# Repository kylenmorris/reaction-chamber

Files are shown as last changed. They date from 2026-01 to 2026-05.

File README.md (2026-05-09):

# Reaction Chamber for Pathogen Detection in Crops

Badges, platform, license, status

## About the Project
<!-- ##################### -->

Lorem ipsum dolor sit amet, consectetur adipiscing elit, sed do eiusmod tempor incididunt ut labore et dolore magna aliqua. Ut enim ad minim veniam, quis nostrud exercitation ullamco laboris nisi ut aliquip ex ea commodo consequat. 

## System Architecture
<!-- ##################### -->

### Block Diagram
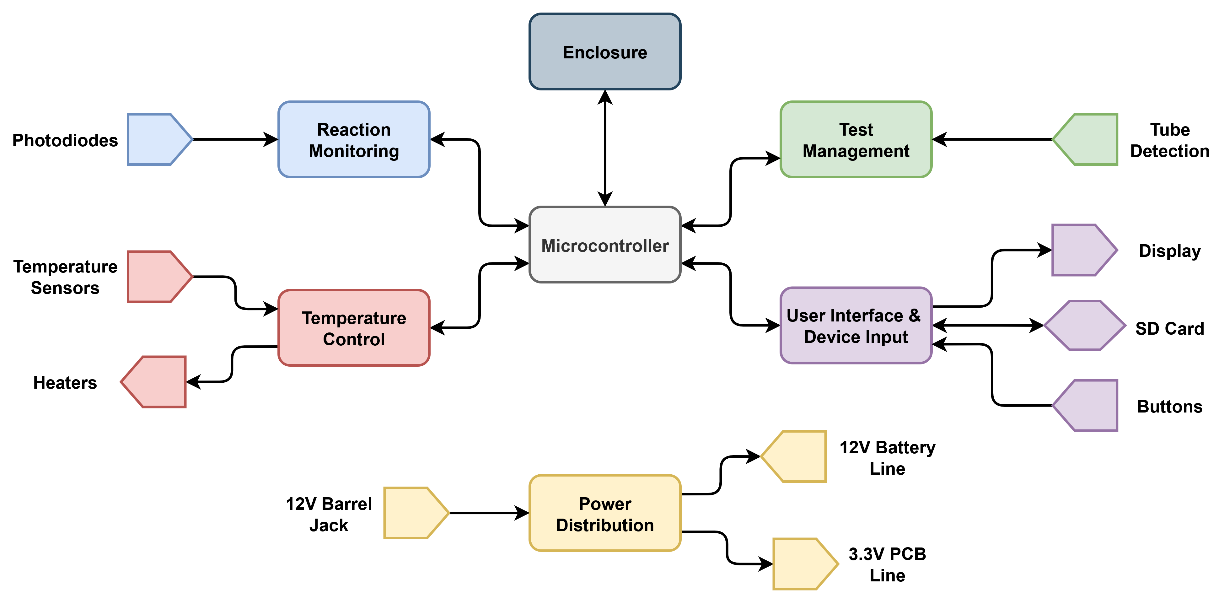
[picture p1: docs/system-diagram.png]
system block diagram


### Images

### PCBs

## Software Architecture
<!-- ##################### -->

### Software Diagram
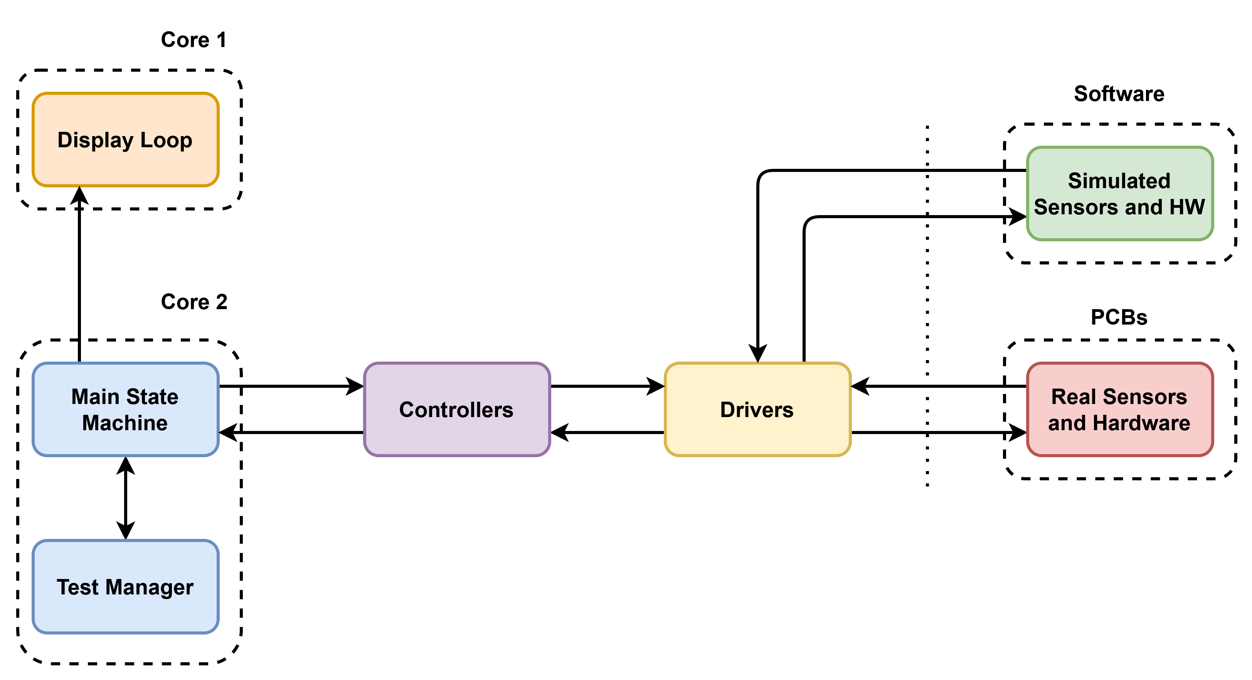
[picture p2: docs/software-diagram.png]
software block diagram


### State Diagram

### Hardware Abstraction

### Other Headers

## Hardware Overview
<!-- ##################### -->

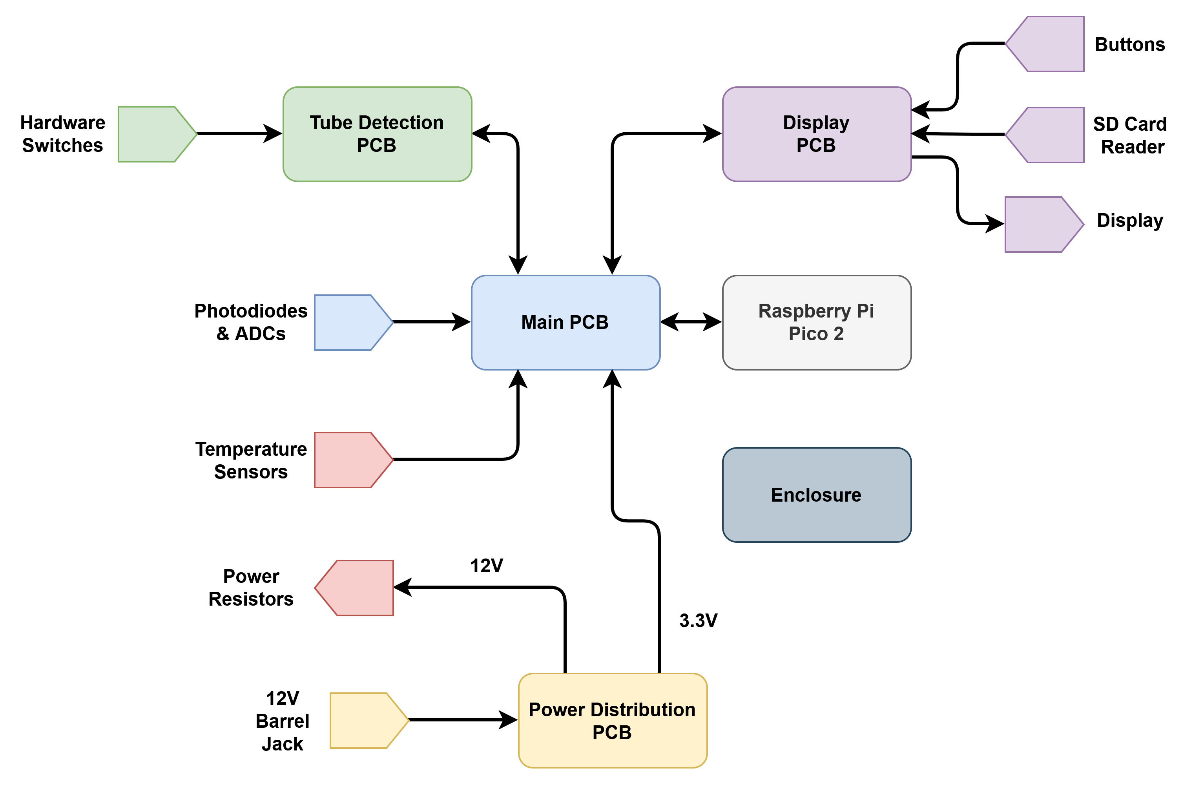
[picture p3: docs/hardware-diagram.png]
hardware block diagram


## Design Decisions
<!-- ##################### -->

## Build and Flash Instructions
<!-- ##################### -->

### Prerequisites
* Raspberry Pi Pico SDK
  ```sh
  installation here
  ```
* CMake
  ```sh
  installation here
  ```

### Compilation and Flashing
While this project does make use of the Raspberry Pi Pico extension, there can be issues using it when first cloning the project. We are using CMake and Ninja for compilation, as is default for the Pico.
After pulling, navigate into the .\code\ directory
```
cd .\code
```
Create the build folder
```
New-Item -ItemType Directory -Name build ; cd build
```
Run CMake with Ninja, and build the project
```
cmake -G Ninja ..
ninja
```

### Running Tests

### License and Acknowledgements
MIT License 

Built for an industry partner as part of a capstone project. The implementation is original work.

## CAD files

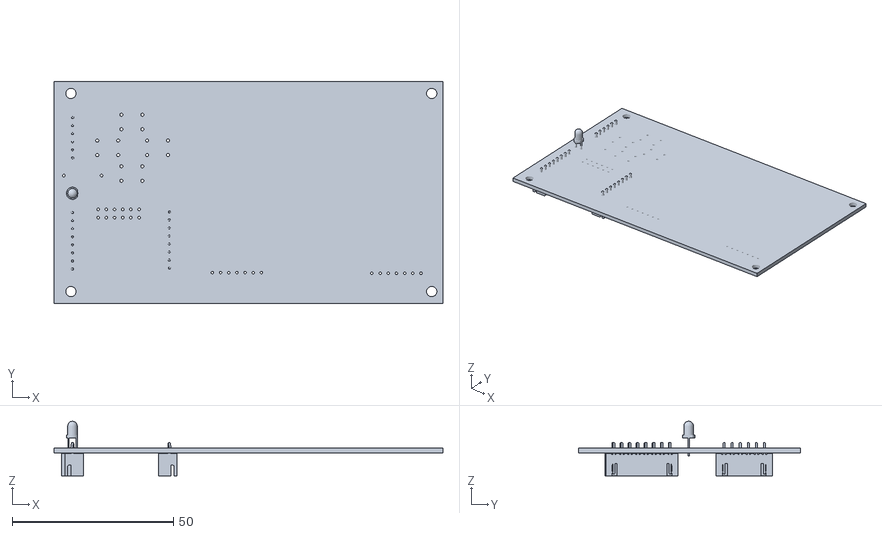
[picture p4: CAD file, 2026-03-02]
PCB/display-pcb/display-pcb.stl
120.8 x 69.0 x 17.0

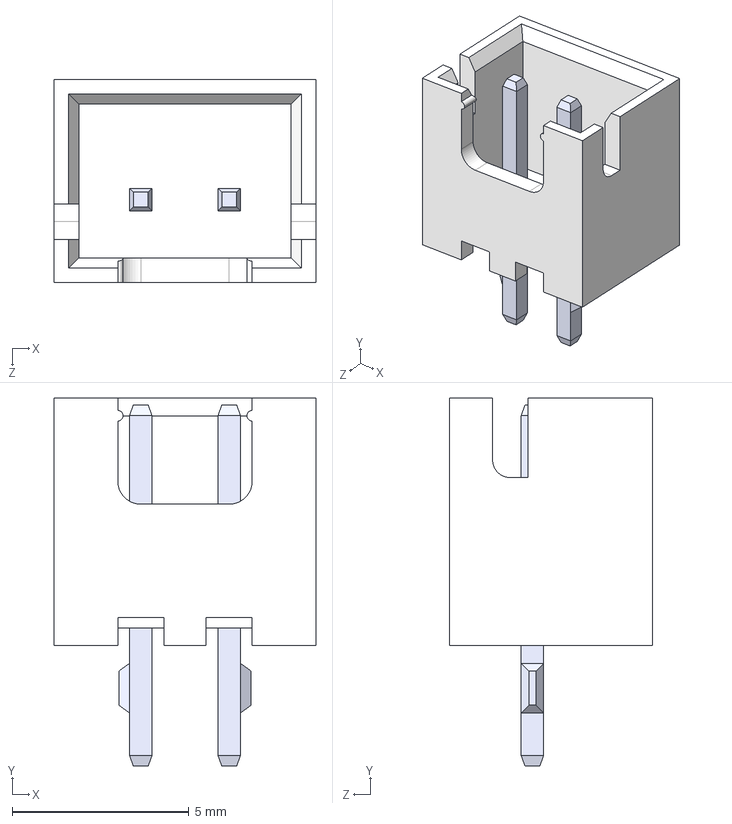
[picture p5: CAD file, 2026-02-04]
PCB/KiCad_parts/B2B_XH_A/B2B-XH-A.step
7.40 x 10.4 x 5.75 mm

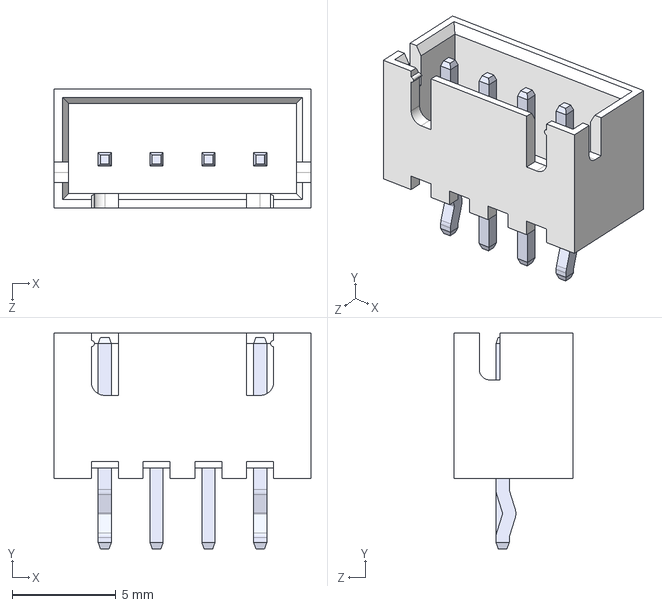
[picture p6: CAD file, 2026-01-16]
PCB/KiCad_parts/B4B_XH_A/B4B-XH-A.step
12.4 x 10.4 x 5.75 mm

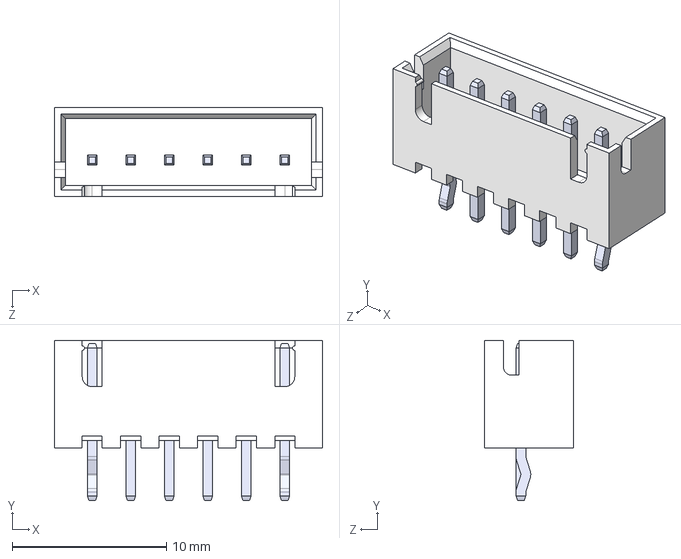
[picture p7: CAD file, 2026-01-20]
PCB/KiCad_parts/B6B-XH-A/B6B-XH-A.step
17.4 x 10.4 x 5.75 mm

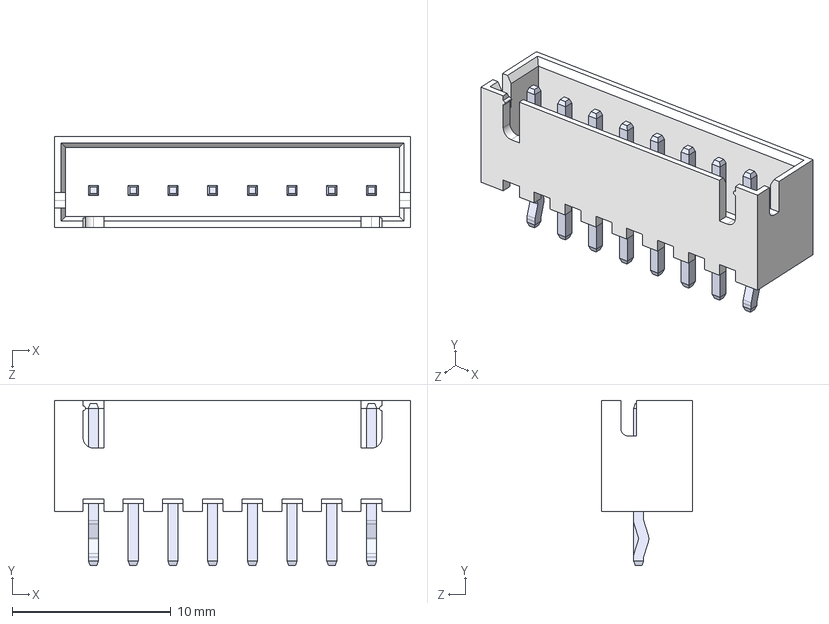
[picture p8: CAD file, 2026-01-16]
PCB/KiCad_parts/B8B_XH_A/B8B-XH-A.step
22.4 x 10.4 x 5.75 mm

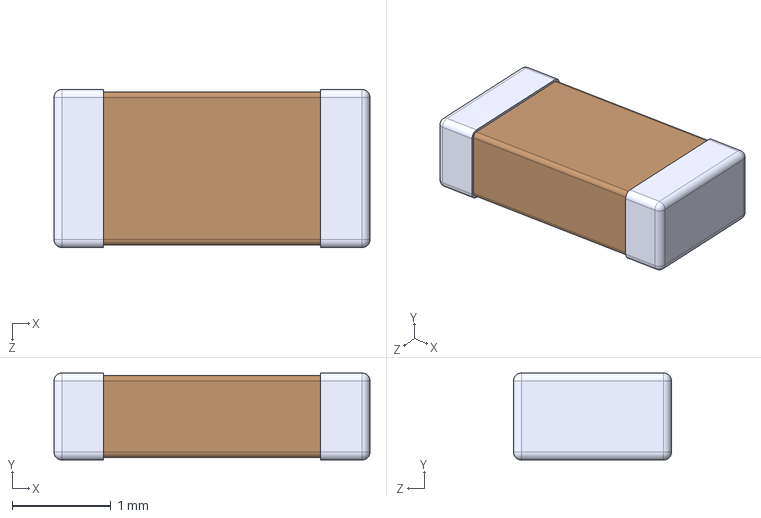
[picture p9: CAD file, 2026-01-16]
PCB/KiCad_parts/C1206C104K5RACTU/C1206C104K5RACTU.step
3.20 x 0.88 x 1.60 mm

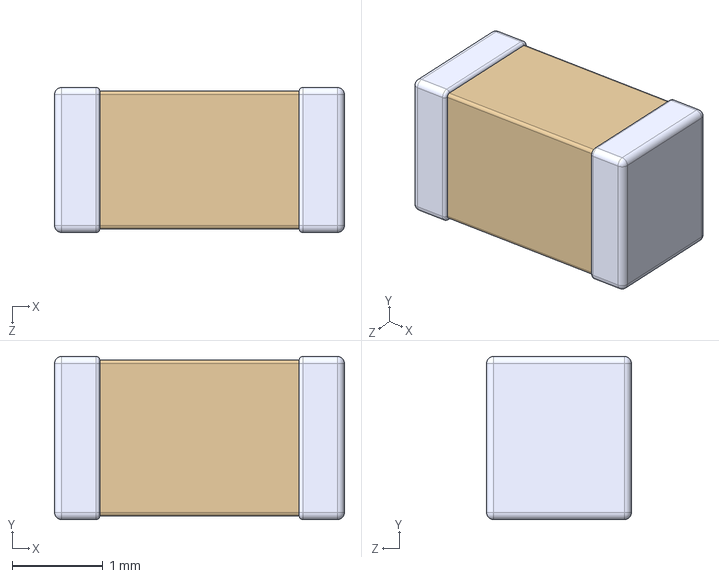
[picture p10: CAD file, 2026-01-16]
PCB/KiCad_parts/CL31A106KBHNNNE/CL31A106KBHNNNE.step
3.20 x 1.80 x 1.60 mm

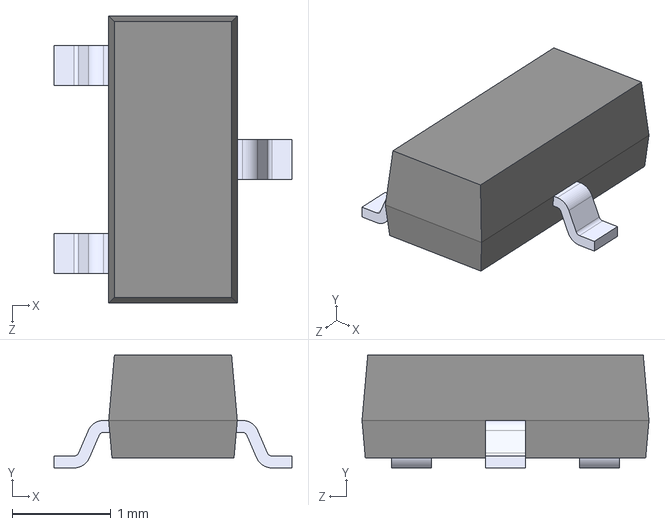
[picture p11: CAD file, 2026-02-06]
PCB/KiCad_parts/DMG2305UX_7/DMG2305UX-7.step
2.40 x 1.14 x 2.90 mm

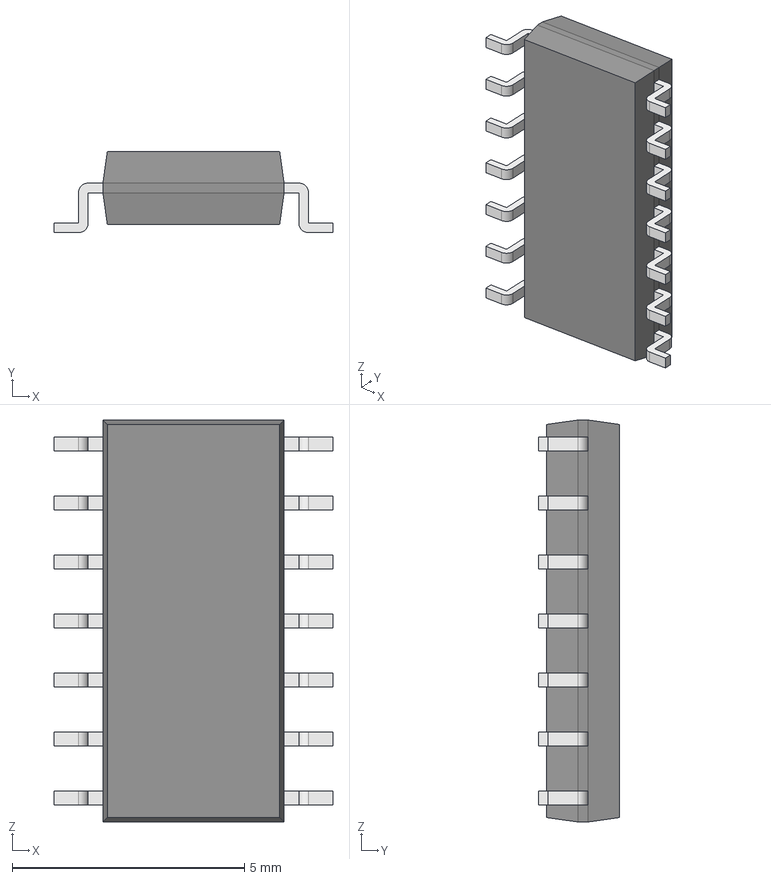
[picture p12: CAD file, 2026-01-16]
PCB/KiCad_parts/LMC660CMX_NOPB/LMC660CM.step
6.00 x 1.75 x 8.65 mm
Body001 (Mirror #1) x 7
XY-plane x 12
X-axis x 12

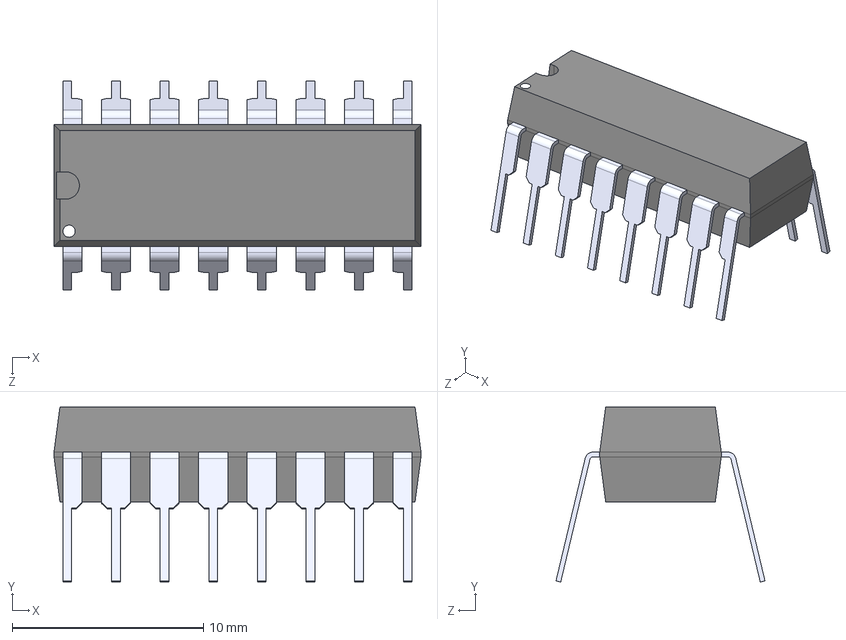
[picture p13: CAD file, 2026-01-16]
PCB/KiCad_parts/MCP3208_CI_P/MCP3208-CI_P.step
19.2 x 9.14 x 10.9 mm

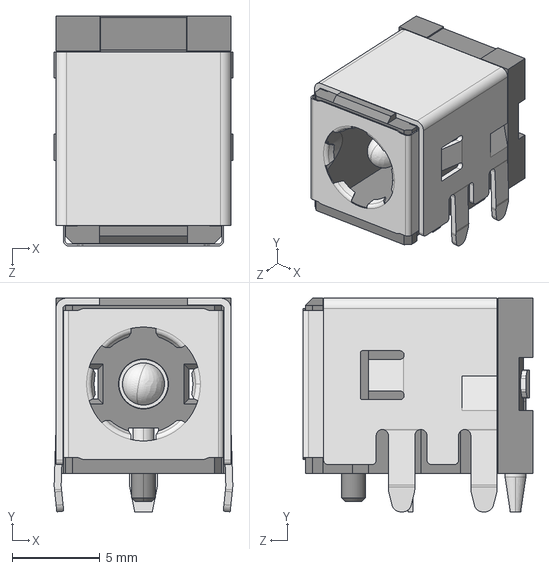
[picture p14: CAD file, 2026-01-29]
PCB/KiCad_parts/PJ_082BH/PJ-082BH.step
10.2 x 12.2 x 13.1 mm

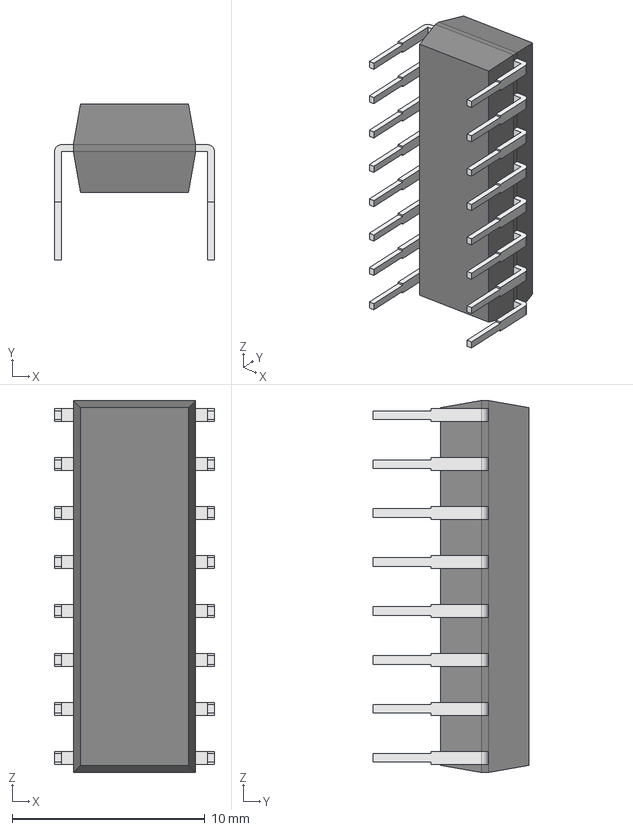
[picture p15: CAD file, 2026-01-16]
PCB/KiCad_parts/SN74HC165N/SN74HC165N.step
8.31 x 8.08 x 19.3 mm
Body001 (Mirror #1) x 9

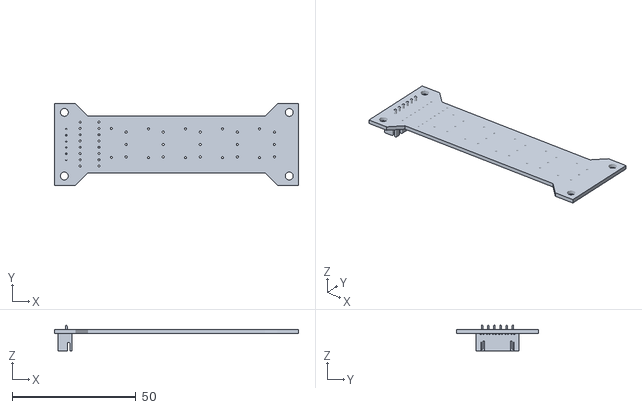
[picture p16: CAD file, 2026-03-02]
PCB/tube_detection_pcb/tube_detection_pcb/tube_detection_pcb.stl
98.8 x 33.0 x 10.4

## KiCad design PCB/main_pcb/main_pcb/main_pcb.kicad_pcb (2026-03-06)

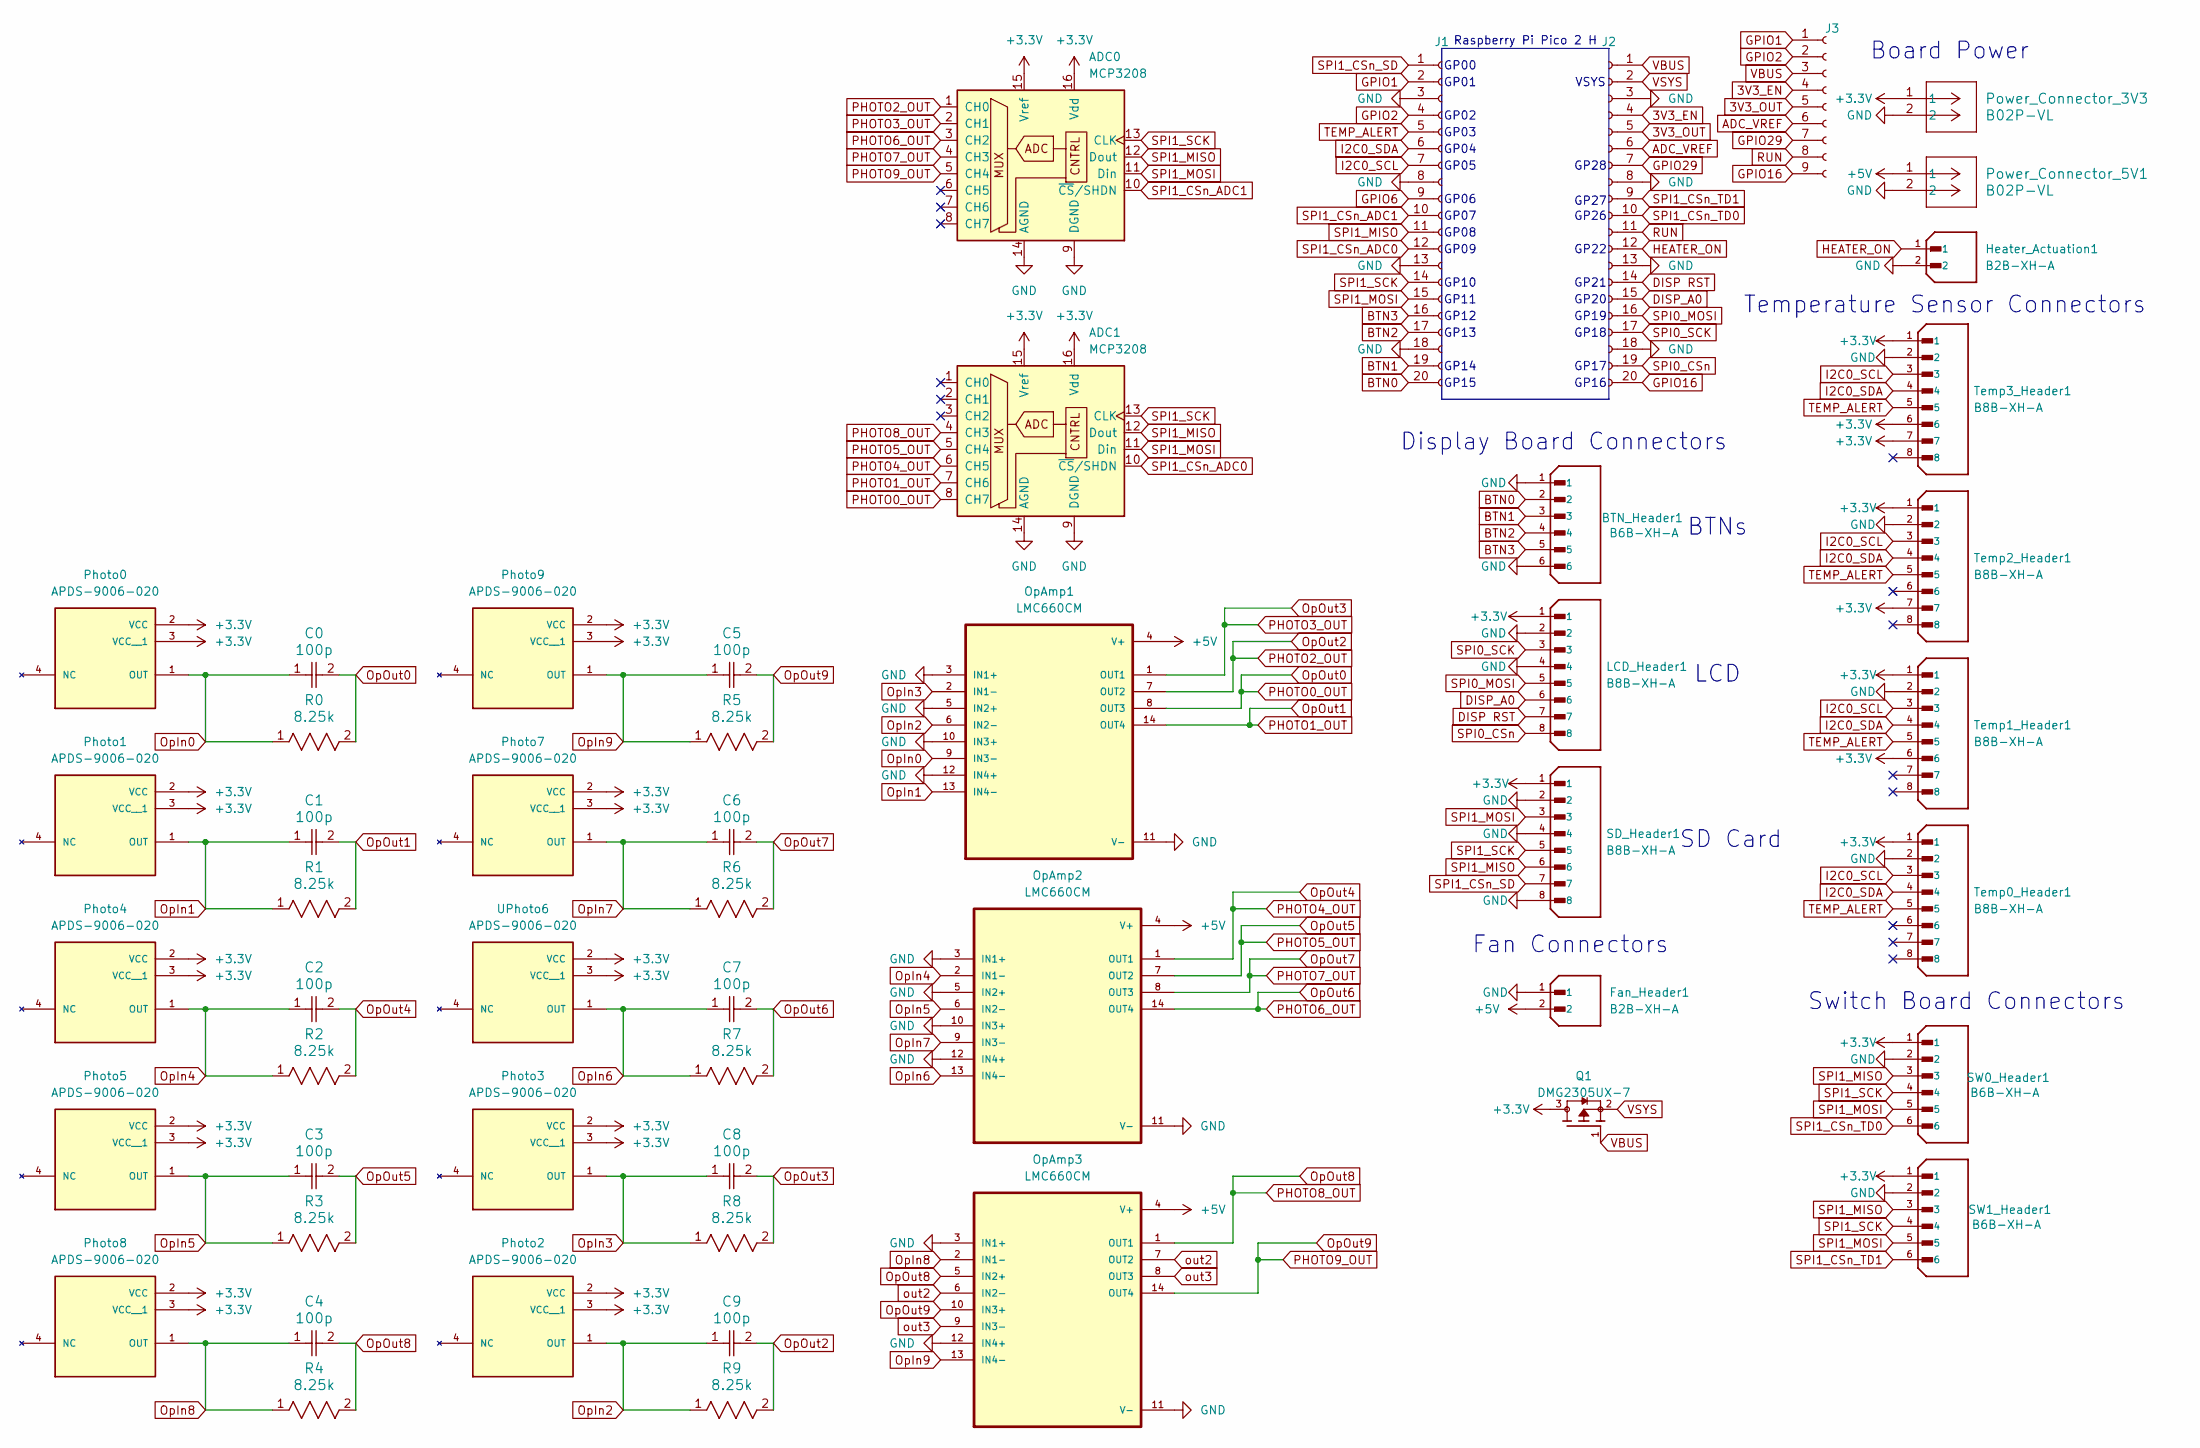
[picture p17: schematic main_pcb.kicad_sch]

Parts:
ADC0, ADC1: MCP3208; DIP254P762X432-16
BTN_Header1: B6B-XH-A; JST_XH_B6B-XH-A_1x06_P2.50mm_Vertical; PARTREV 7/4/21; DigiKey_Part_Number 455-B6B-XH-A-ND
C0, C1, C2, C3, C4, C5, C6, C7, C8, C9: 100p; C_1206_3216Metric_Pad1.33x1.80mm_HandSolder
Fan_Header1: B2B-XH-A; JST_B2B-XH-A; PARTREV N/A
Heater_Actuation1: B2B-XH-A; JST_B2B-XH-A; PARTREV N/A
J1, J2: Conn_01x20_Socket; PinSocket_1x20_P2.54mm_Vertical
J3: Conn_01x09_Socket; PinSocket_1x09_P2.54mm_Vertical
LCD_Header1: B8B-XH-A; JST_XH_B8B-XH-A_1x08_P2.50mm_Vertical; PARTREV 7/4/21
OpAmp1, OpAmp2, OpAmp3: LMC660CM; SOIC127P600X175-14N
Photo0, Photo1, Photo2, Photo3, Photo4, Photo5, Photo7, Photo8, Photo9: APDS-9006-020; photodiode_v4; PARTREV January 16, 2007
Power_Connector_3V3, Power_Connector_5V1: B02P-VL; CONN_B02P-VL_JST
Q1: DMG2305UX-7; SOT91P240X110-3N_DMG2305UX-7; PARTREV 09/2018
R0, R1, R2, R3, R4, R5, R6, R7, R8, R9: 8.25k; YAG_MF25_YAG
SD_Header1: B8B-XH-A; JST_XH_B8B-XH-A_1x08_P2.50mm_Vertical; PARTREV 7/4/21
SW0_Header1, SW1_Header1: B6B-XH-A; JST_XH_B6B-XH-A_1x06_P2.50mm_Vertical; PARTREV 7/4/21; DigiKey_Part_Number 455-B6B-XH-A-ND
Temp0_Header1, Temp1_Header1, Temp2_Header1, Temp3_Header1: B8B-XH-A; JST_XH_B8B-XH-A_1x08_P2.50mm_Vertical; PARTREV 7/4/21
UPhoto6: APDS-9006-020; photodiode_v4; PARTREV January 16, 2007

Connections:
3V3_EN: J2.4, J3.4
3V3_OUT: J2.5, J3.5
+3.3V: ADC0.15 (Vref), ADC0.16 (Vdd), ADC1.15 (Vref), ADC1.16 (Vdd), LCD_Header1.1, Photo0.2 (VCC), Photo0.3 (VCC__1), Photo1.2 (VCC), Photo1.3 (VCC__1), Photo2.2 (VCC), Photo2.3 (VCC__1), Photo3.2 (VCC), Photo3.3 (VCC__1), Photo4.2 (VCC), Photo4.3 (VCC__1), Photo5.2 (VCC), Photo5.3 (VCC__1), Photo7.2 (VCC), Photo7.3 (VCC__1), Photo8.2 (VCC), Photo8.3 (VCC__1), Photo9.2 (VCC), Photo9.3 (VCC__1), Power_Connector_3V3.1, Q1.3, SD_Header1.1, SW0_Header1.1, SW1_Header1.1, Temp0_Header1.1, Temp1_Header1.1, Temp1_Header1.6, Temp2_Header1.1, Temp2_Header1.7, Temp3_Header1.1, Temp3_Header1.6, Temp3_Header1.7, UPhoto6.2 (VCC), UPhoto6.3 (VCC__1)
+5V: Fan_Header1.2, OpAmp1.4 (V+), OpAmp2.4 (V+), OpAmp3.4 (V+), Power_Connector_5V1.1
ADC_VREF: J2.6, J3.6
BTN0: BTN_Header1.2, J1.20
BTN1: BTN_Header1.3, J1.19
BTN2: BTN_Header1.4, J1.17
BTN3: BTN_Header1.5, J1.16
DISP RST: J2.14, LCD_Header1.7
DISP_A0: J2.15, LCD_Header1.6
GND: ADC0.9 (DGND), ADC0.14 (AGND), ADC1.9 (DGND), ADC1.14 (AGND), BTN_Header1.1, BTN_Header1.6, Fan_Header1.1, Heater_Actuation1.2, J1.3, J1.8, J1.13, J1.18, J2.3, J2.8, J2.13, J2.18, LCD_Header1.2, LCD_Header1.4, OpAmp1.3 (IN1+), OpAmp1.5 (IN2+), OpAmp1.10 (IN3+), OpAmp1.11 (V-), OpAmp1.12 (IN4+), OpAmp2.3 (IN1+), OpAmp2.5 (IN2+), OpAmp2.10 (IN3+), OpAmp2.11 (V-), OpAmp2.12 (IN4+), OpAmp3.3 (IN1+), OpAmp3.11 (V-), OpAmp3.12 (IN4+), Power_Connector_3V3.2, Power_Connector_5V1.2, SD_Header1.2, SD_Header1.4, SD_Header1.8, SW0_Header1.2, SW1_Header1.2, Temp0_Header1.2, Temp1_Header1.2, Temp2_Header1.2, Temp3_Header1.2
GPIO1: J1.2, J3.1
GPIO2: J1.4, J3.2
GPIO6: J1.9
GPIO16: J2.20, J3.9
GPIO29: J2.7, J3.7
HEATER_ON: Heater_Actuation1.1, J2.12
I2C0_SCL: J1.7, Temp0_Header1.3, Temp1_Header1.3, Temp2_Header1.3, Temp3_Header1.3
I2C0_SDA: J1.6, Temp0_Header1.4, Temp1_Header1.4, Temp2_Header1.4, Temp3_Header1.4
OpIn0: C0.1, OpAmp1.9 (IN3-), Photo0.1 (OUT), R0.1
OpIn1: C1.1, OpAmp1.13 (IN4-), Photo1.1 (OUT), R1.1
OpIn2: C9.1, OpAmp1.6 (IN2-), Photo2.1 (OUT), R9.1
OpIn3: C8.1, OpAmp1.2 (IN1-), Photo3.1 (OUT), R8.1
OpIn4: C2.1, OpAmp2.2 (IN1-), Photo4.1 (OUT), R2.1
OpIn5: C3.1, OpAmp2.6 (IN2-), Photo5.1 (OUT), R3.1
OpIn6: C7.1, OpAmp2.13 (IN4-), R7.1, UPhoto6.1 (OUT)
OpIn7: C6.1, OpAmp2.9 (IN3-), Photo7.1 (OUT), R6.1
OpIn8: C4.1, OpAmp3.2 (IN1-), Photo8.1 (OUT), R4.1
OpIn9: C5.1, OpAmp3.13 (IN4-), Photo9.1 (OUT), R5.1
OpOut0: ADC1.8 (CH7), C0.2, OpAmp1.8 (OUT3), R0.2
OpOut1: ADC1.7 (CH6), C1.2, OpAmp1.14 (OUT4), R1.2
OpOut2: ADC0.1 (CH0), C9.2, OpAmp1.7 (OUT2), R9.2
OpOut3: ADC0.2 (CH1), C8.2, OpAmp1.1 (OUT1), R8.2
OpOut4: ADC1.6 (CH5), C2.2, OpAmp2.1 (OUT1), R2.2
OpOut5: ADC1.5 (CH4), C3.2, OpAmp2.7 (OUT2), R3.2
OpOut6: ADC0.3 (CH2), C7.2, OpAmp2.14 (OUT4), R7.2
OpOut7: ADC0.4 (CH3), C6.2, OpAmp2.8 (OUT3), R6.2
OpOut8: ADC1.4 (CH3), C4.2, OpAmp3.1 (OUT1), OpAmp3.5 (IN2+), R4.2
OpOut9: ADC0.5 (CH4), C5.2, OpAmp3.10 (IN3+), OpAmp3.14 (OUT4), R5.2
RUN: J2.11, J3.8
SPI0_CSn: J2.19, LCD_Header1.8
SPI0_MOSI: J2.16, LCD_Header1.5
SPI0_SCK: J2.17, LCD_Header1.3
SPI1_CSn_ADC0: ADC1.10 (~CS/SHDN), J1.12
SPI1_CSn_ADC1: ADC0.10 (~CS/SHDN), J1.10
SPI1_CSn_SD: J1.1, SD_Header1.7
SPI1_CSn_TD0: J2.10, SW0_Header1.6
SPI1_CSn_TD1: J2.9, SW1_Header1.6
SPI1_MISO: ADC0.12 (Dout), ADC1.12 (Dout), J1.11, SD_Header1.6, SW0_Header1.3, SW1_Header1.3
SPI1_MOSI: ADC0.11 (Din), ADC1.11 (Din), J1.15, SD_Header1.3, SW0_Header1.5, SW1_Header1.5
SPI1_SCK: ADC0.13 (CLK), ADC1.13 (CLK), J1.14, SD_Header1.5, SW0_Header1.4, SW1_Header1.4
TEMP_ALERT: J1.5, Temp0_Header1.5, Temp1_Header1.5, Temp2_Header1.5, Temp3_Header1.5
VBUS: J2.1, J3.3, Q1.1
VSYS: J2.2, Q1.2
out2: OpAmp3.6 (IN2-), OpAmp3.7 (OUT2)
out3: OpAmp3.8 (OUT3), OpAmp3.9 (IN3-)

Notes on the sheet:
GP18
GP06
GP11
Switch Board Connectors
GP12
GP27
SD Card
GP22
Fan Connectors
GP10
GP15
GP03
GP09
GP21
VSYS
GP05
GP16
Display Board Connectors
GP04
GP02
GP13
Temperature Sensor Connectors
GP14
GP17
GP00
Board Power
GP19
GP28
LCD
GP20
GP07
GP08
BTNs
GP26
Raspberry Pi Pico 2 H
GP01

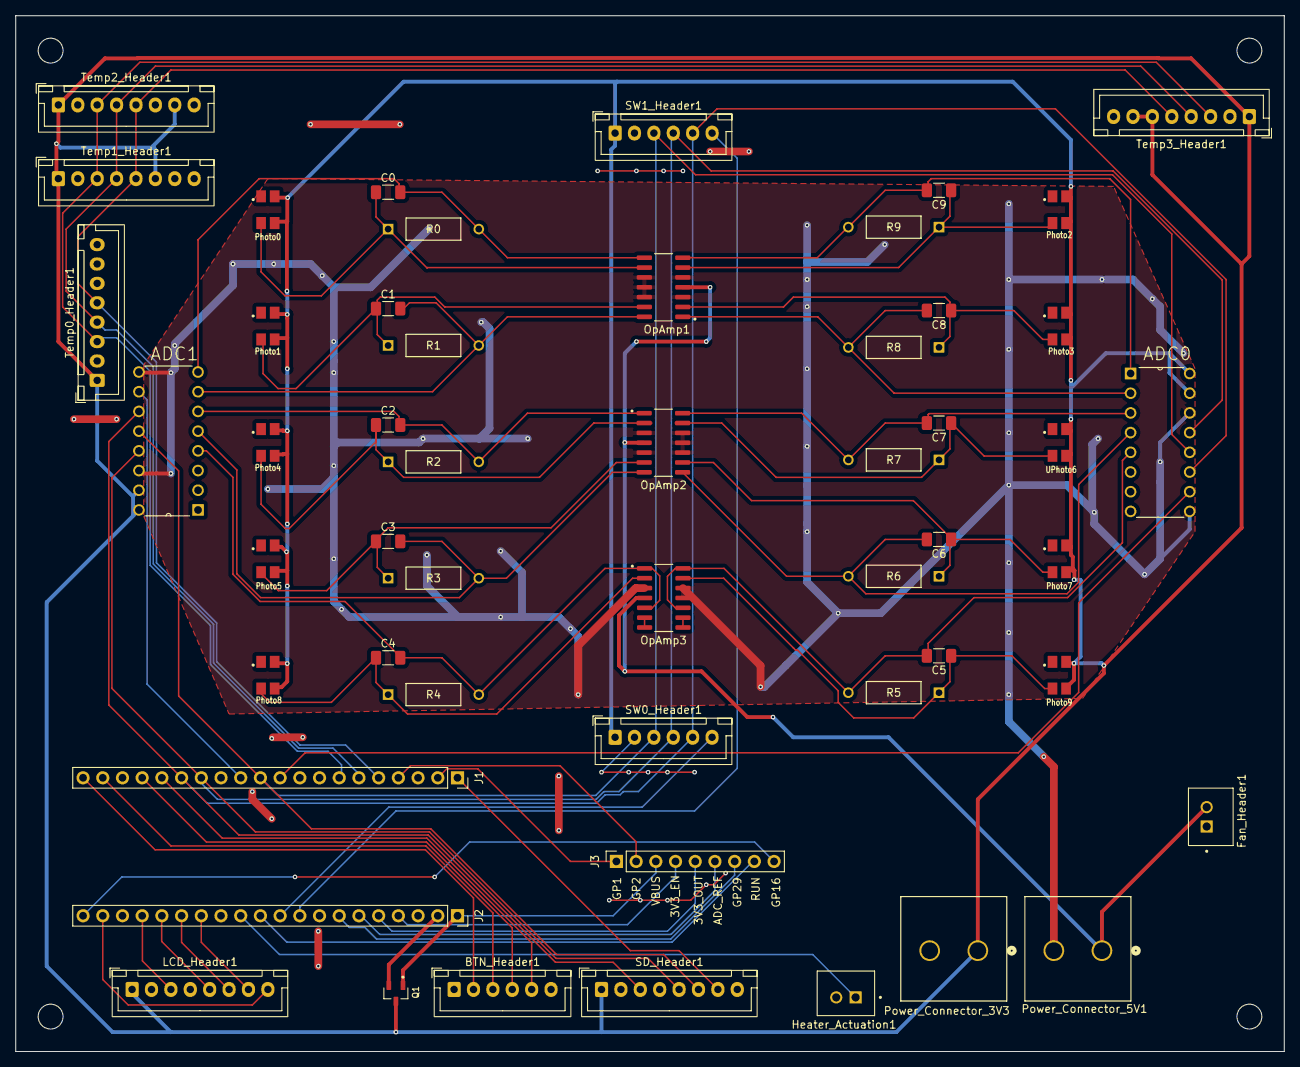
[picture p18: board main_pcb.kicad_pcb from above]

Board: 2 copper layers, 163.5 x 133.5 mm, 52 parts (0 on the bottom side), 56 nets.

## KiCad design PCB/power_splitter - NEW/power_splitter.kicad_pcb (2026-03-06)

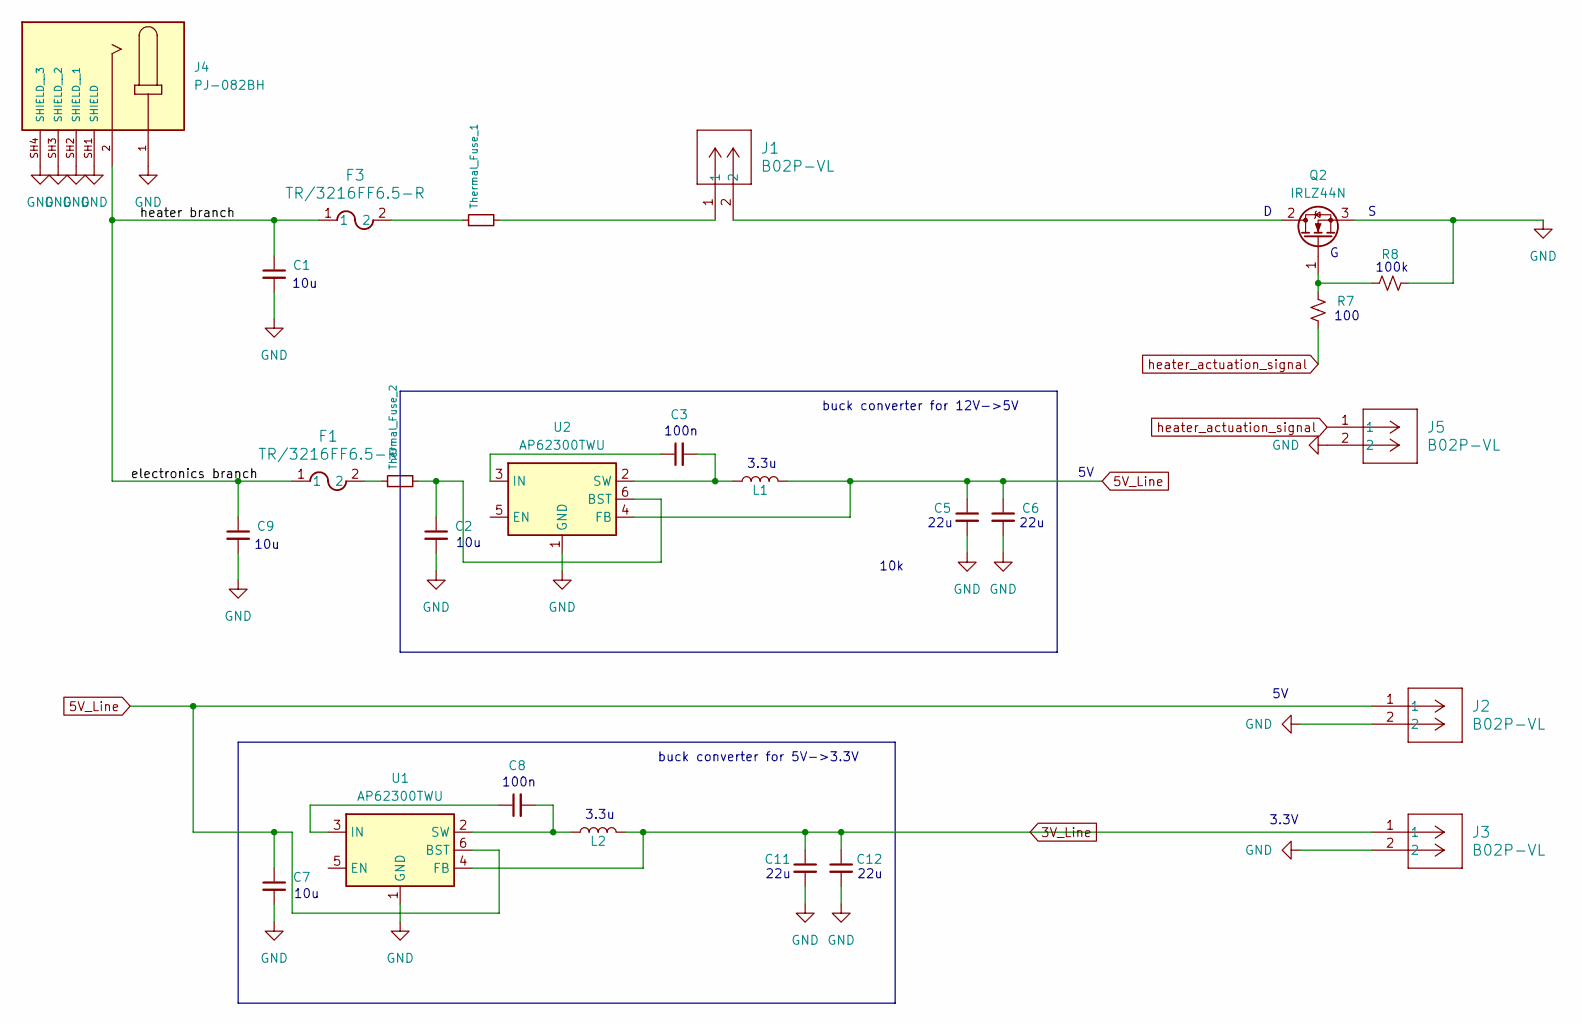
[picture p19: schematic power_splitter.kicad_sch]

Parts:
C1, C2, C3, C5, C6, C7, C8, C9, C11, C12: C_Small; C_1206_3216Metric_Pad1.33x1.80mm_HandSolder
F1, F3: TR/3216FF6.5-R; FUS_CB_3216FF
J1, J2, J3: B02P-VL; CONN_B02P-VL_JST
J4: PJ-082BH; SAMESKY_PJ-082BH; PARTREV 1.06
J5: B02P-VL; JST_NV_B02P-NV_1x02_P5.00mm_Vertical
L1, L2: L; L_Axial_L7.0mm_D3.3mm_P5.08mm_Vertical_Fastron_MICC
Q2: IRLZ44N; TO-220-3_Vertical
R7, R8: R_Small_US; YAG_MF25_YAG
Thermal_Fuse_1, Thermal_Fuse_2: R_Small; YAG_MF25_YAG
U1, U2: AP62300TWU; TSOT-23-6

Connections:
3V_Line: C11.1, C12.1, J3.1, L2.2, U1.4 (FB)
5V_Line: C5.1, C6.1, C7.1, J2.1, L1.2, U1.6 (BST), U2.4 (FB)
/electronics branch: C1.1, C9.1, F1.1, F3.1, J4.2
GND: C1.2, C2.2, C5.2, C6.2, C7.2, C9.2, C11.2, C12.2, J2.2, J3.2, J4.1, J4.SH1 (SHIELD), J4.SH2 (SHIELD__1), J4.SH3 (SHIELD__2), J4.SH4 (SHIELD__3), J5.2, Q2.3 (S), R8.2, U1.1 (GND), U2.1 (GND)
unnamed: F1.2, Thermal_Fuse_2.1
unnamed: F3.2, Thermal_Fuse_1.1
unnamed: J1.1, Thermal_Fuse_1.2
unnamed: J1.2, Q2.2 (D)
unnamed: Q2.1 (G), R7.1, R8.1
unnamed: C8.1, U1.3 (IN)
unnamed: C8.2, L2.1, U1.2 (SW)
unnamed: C2.1, Thermal_Fuse_2.2, U2.6 (BST)
unnamed: C3.1, U2.3 (IN)
unnamed: C3.2, L1.1, U2.2 (SW)
heater_actuation_signal: J5.1, R7.2

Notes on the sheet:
10u
100n
100
100k
10k
22u
3.3u
3.3V
buck converter for 12V->5V
buck converter for 5V->3.3V

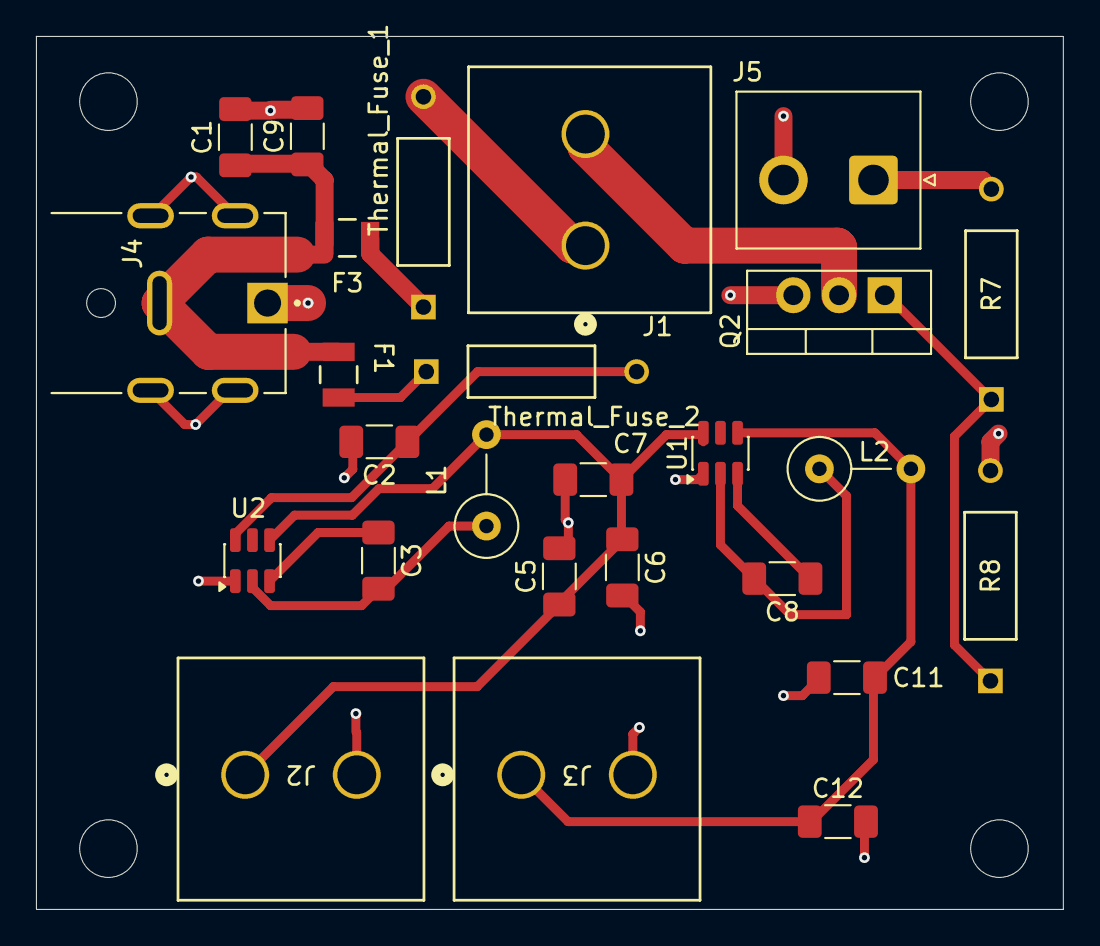
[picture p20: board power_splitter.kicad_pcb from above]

Board: 2 copper layers, 57.1 x 48.5 mm, 26 parts (0 on the bottom side), 15 nets.

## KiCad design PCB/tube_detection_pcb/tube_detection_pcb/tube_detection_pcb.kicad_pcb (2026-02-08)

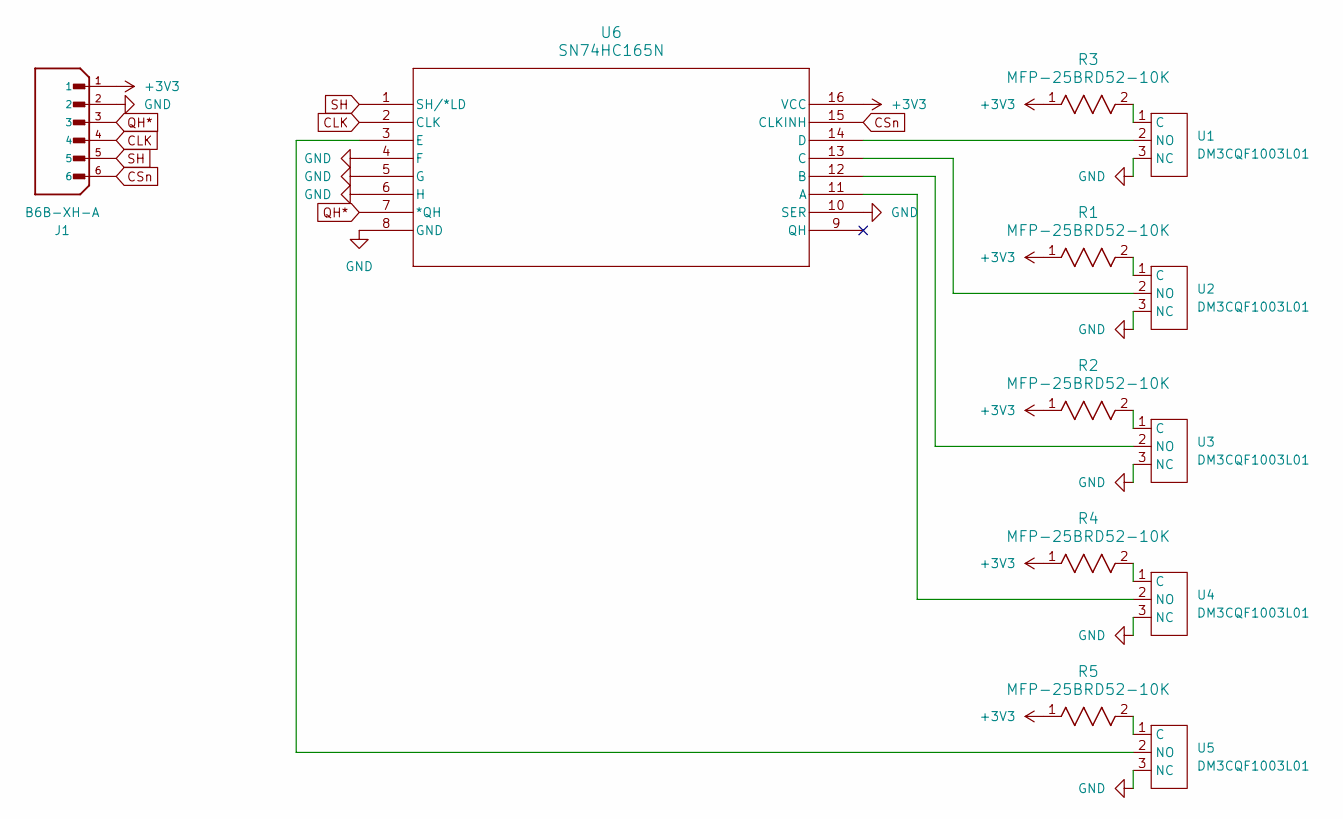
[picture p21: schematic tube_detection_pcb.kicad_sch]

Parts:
J1: B6B-XH-A; JST_XH_B6B-XH-A_1x06_P2.50mm_Vertical; PARTREV 7/4/21; DigiKey_Part_Number 455-B6B-XH-A-ND
R1, R2, R3, R4, R5: MFP-25BRD52-10K; YAG_MF25_YAG
U1, U2, U3, U4, U5: DM3CQF1003L01
U6: SN74HC165N; N16

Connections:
+3V3: J1.1, R1.1, R2.1, R3.1, R4.1, R5.1, U6.16 (VCC)
CLK: J1.4, U6.2 (CLK)
CSn: J1.6, U6.15 (CLKINH)
GND: J1.2, U1.3 (NC), U2.3 (NC), U3.3 (NC), U4.3 (NC), U5.3 (NC), U6.4 (F), U6.5 (G), U6.6 (H), U6.8 (GND), U6.10 (SER)
unnamed: R3.2, U1.1 (C)
unnamed: U1.2 (NO), U6.14 (D)
unnamed: R1.2, U2.1 (C)
unnamed: U2.2 (NO), U6.13 (C)
unnamed: R2.2, U3.1 (C)
unnamed: U3.2 (NO), U6.12 (B)
unnamed: R4.2, U4.1 (C)
unnamed: U4.2 (NO), U6.11 (A)
unnamed: R5.2, U5.1 (C)
unnamed: U5.2 (NO), U6.3 (E)
QH*: J1.3, U6.7 (*QH)
SH: J1.5, U6.1 (SH/*LD)

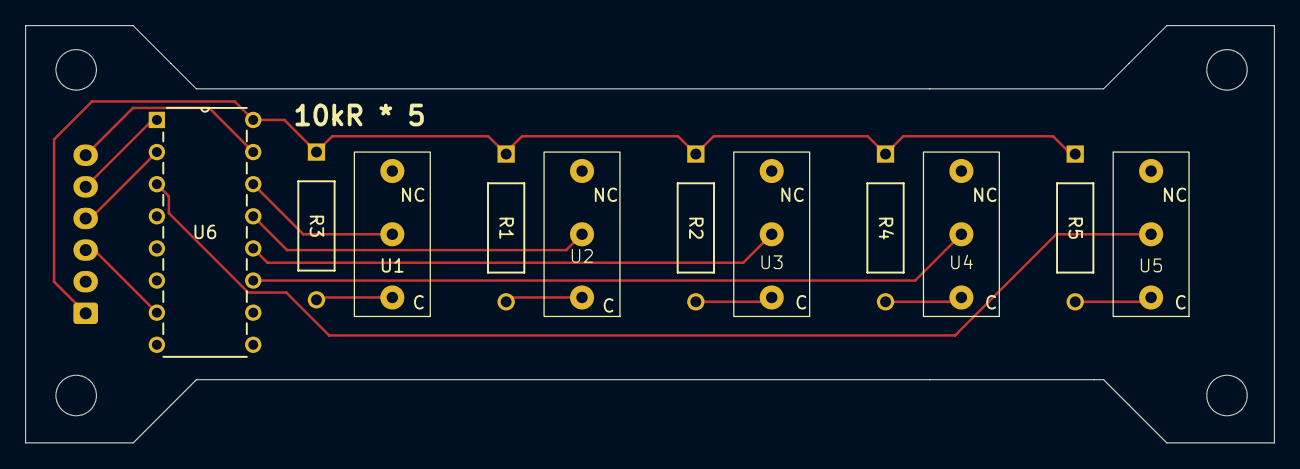
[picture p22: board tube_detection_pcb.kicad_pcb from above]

Board: 2 copper layers, 98.8 x 33.0 mm, 12 parts (1 on the bottom side), 16 nets.

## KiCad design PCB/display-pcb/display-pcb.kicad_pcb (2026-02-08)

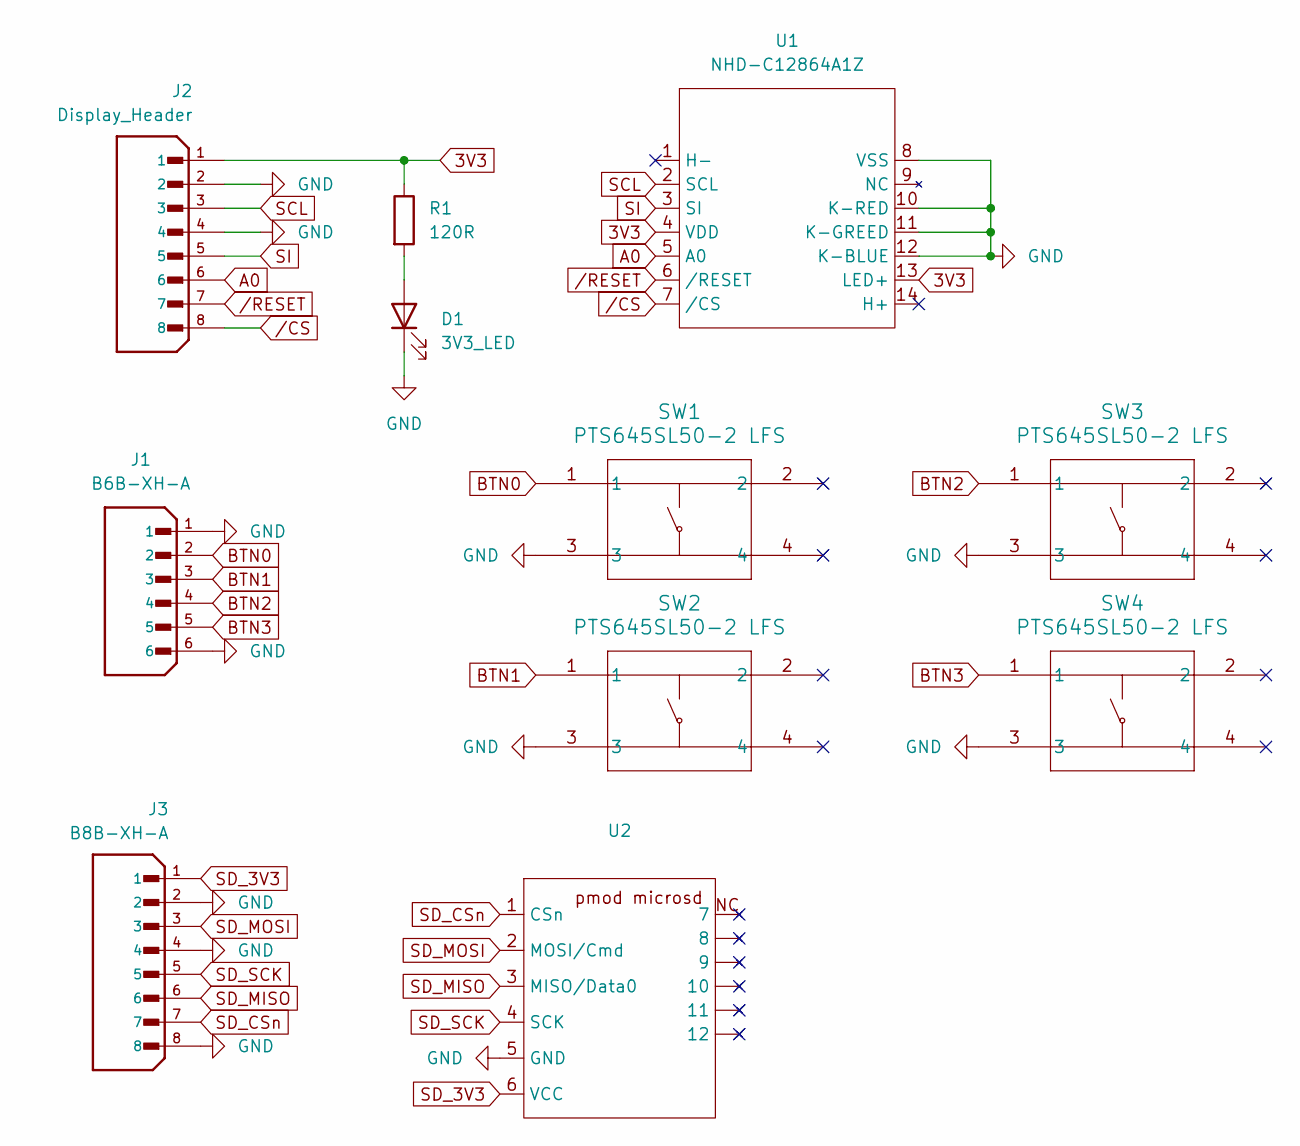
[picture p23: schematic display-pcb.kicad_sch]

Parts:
D1: 3V3_LED; LED_D3.0mm
J1: B6B-XH-A; JST_XH_B6B-XH-A_1x06_P2.50mm_Vertical; PARTREV 7/4/21; DigiKey_Part_Number 455-B6B-XH-A-ND
J2: Display_Header; JST_XH_B8B-XH-A_1x08_P2.50mm_Vertical; PARTREV 7/4/21
J3: B8B-XH-A; JST_XH_B8B-XH-A_1x08_P2.50mm_Vertical; PARTREV 7/4/21
R1: 120R; YAG_MF25_YAG
SW1, SW2, SW3, SW4: PTS645SL50-2 LFS; PTS654S_CNK
U1: NHD-C12864A1Z
U2: pmod-microsd

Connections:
3V3: J2.1, R1.1, U1.4 (VDD), U1.13 (LED+)
A0: J2.6, U1.5 (A0)
BTN0: J1.2, SW1.1
BTN1: J1.3, SW2.1
BTN2: J1.4, SW3.1
BTN3: J1.5, SW4.1
GND: D1.1 (K), J1.1, J1.6, J2.2, J2.4, J3.2, J3.4, J3.8, SW1.3, SW2.3, SW3.3, SW4.3, U1.8 (VSS), U1.10 (K-RED), U1.11 (K-GREED), U1.12 (K-BLUE), U2.5 (GND)
unnamed: D1.2 (A), R1.2
SCL: J2.3, U1.2 (SCL)
SD_3V3: J3.1, U2.6 (VCC)
SD_CSn: J3.7, U2.1 (CSn)
SD_MISO: J3.6, U2.3 (MISO/Data0)
SD_MOSI: J3.3, U2.2 (MOSI/Cmd)
SD_SCK: J3.5, U2.4 (SCK)
SI: J2.5, U1.3 (SI)
/CS: J2.8, U1.7 (/CS)
/RESET: J2.7, U1.6 (/RESET)

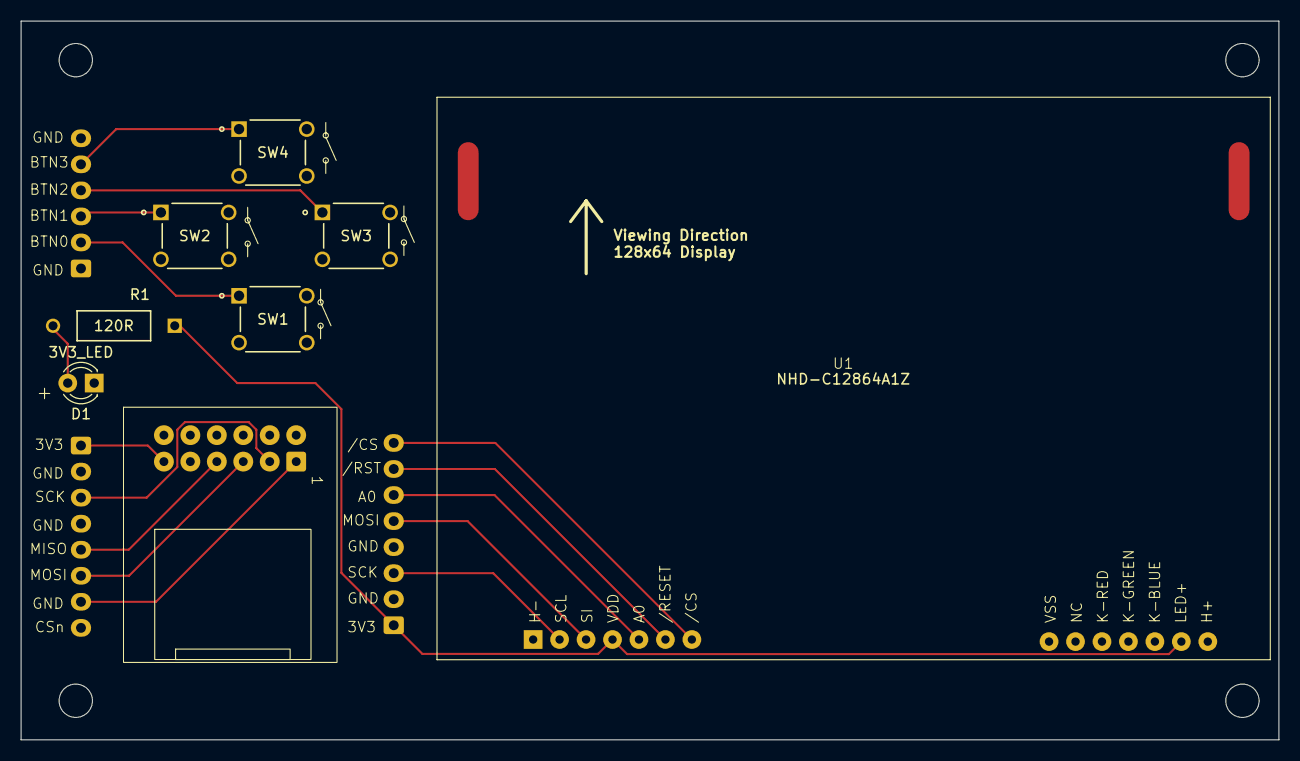
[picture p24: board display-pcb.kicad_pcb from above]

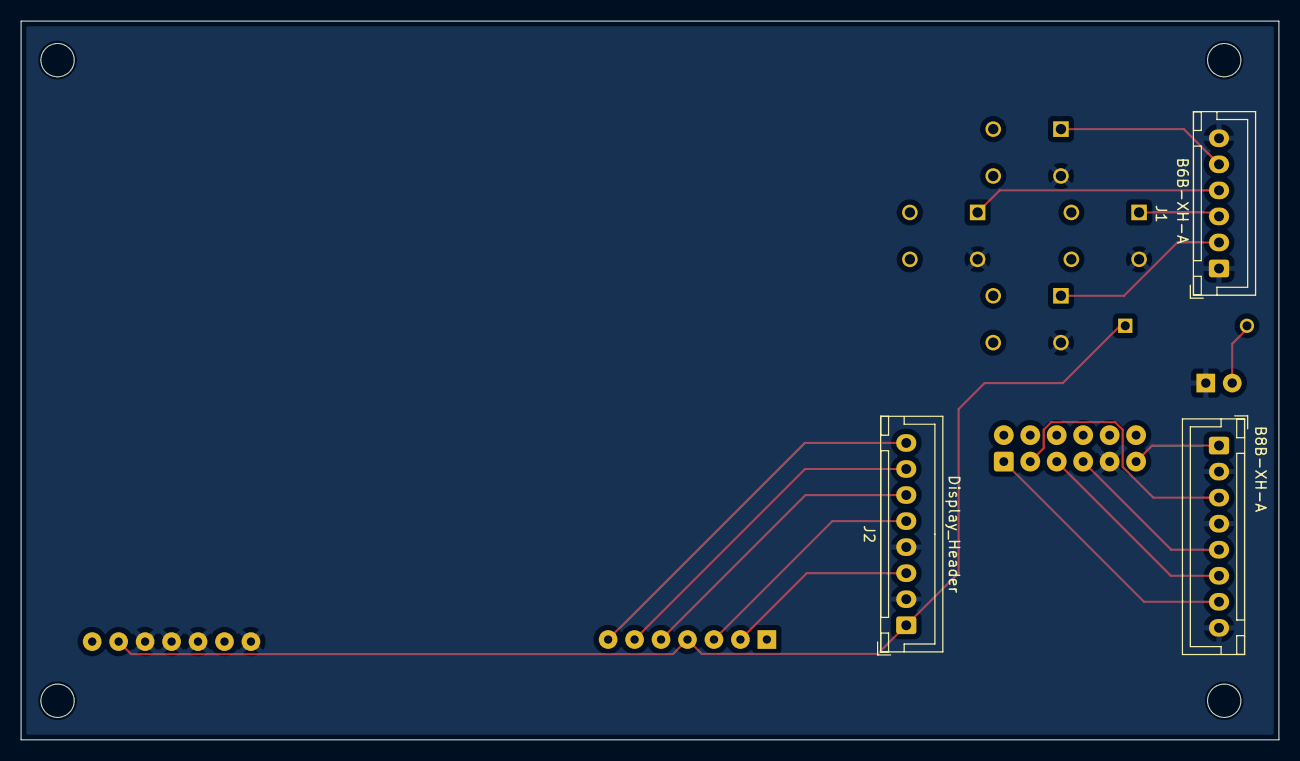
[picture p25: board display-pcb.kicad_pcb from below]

Board: 2 copper layers, 120.8 x 69.0 mm, 11 parts (3 on the bottom side), 17 nets.

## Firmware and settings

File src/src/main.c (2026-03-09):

#include "data_structs.h"
#include "drivers.h"

// **Note** pico/stdlib.h IS needed despite clangd saying otherwise
#include "pico/stdlib.h"     
#include "pico/multicore.h"
#include <hardware/gpio.h>
#include <hardware/spi.h>
#include <stdio.h>
#include <sys/_intsup.h>

#include "constants.h"
#include <stdbool.h>

#include "system_state_loop.h"

// Needed for glcd
void delay_ms(unsigned int ms) {
    sleep_ms(ms);
}

// Second core will update display
void core1_entry() {
    while (true) {      
        run_system_state_loop_core1();

        sleep_ms(SYSTEM_DELAY_MS);
    }
}

int main() {

    // Set up pins, SPI, I2C, etc
    board_setup();

    printf("System booting...\n");

    sleep_ms(SYSTEM_DELAY_MS * 5);

    // Hold up and down to enter debug
    // if (!hw_button_get_raw(BUTTON_PINS[UP])
    //     && !hw_button_get_raw(BUTTON_PINS[UP])) {
    //         DEBUG_MODE = true; // enable some menu items
    // }

    // Run the display on core 1
    multicore_launch_core1(core1_entry);

    // Show the boot screen
    // sleep_ms(200);

    while (true) {      
        run_system_state_loop_core0();

        sleep_ms(SYSTEM_DELAY_MS);
    }
}

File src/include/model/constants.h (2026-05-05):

#ifndef CONSTANTS_H
#define CONSTANTS_H

#include "compilation_variables.h"
#include <stdint.h>

// ####################################
// SYSTEM DEFINITIONS
// ####################################

#define SYSTEM_DELAY_MS 10 // Main loop delay in milliseconds

#define LOW 0
#define HIGH 1

#ifdef PRINT_DEBUG
    #define DEBUG_LOG(fmt, ...) printf("[DEBUG] " fmt "\n", ##__VA_ARGS__)
#else
    #define DEBUG_LOG(fmt, ...)
#endif

#ifdef MASTER_SIMULATION_MODE
    #undef USE_HW_PICO
    #undef USE_HW_BUTTONS
    #undef USE_HW_HEATER
    #undef USE_HW_TEMP_SENS
    #undef USE_HW_OPTICAL
    #undef USE_HW_TUBE_SENS
    #undef USE_HW_DISPLAY
    #undef USE_HW_SD
    #define IS_SIMULATING true
#else
    #define IS_SIMULATING false
#endif

// ####################################
// REACTION CONSTANTS
// ####################################

#define NUM_TUBES 10

#define NUM_TEMP_SENSORS 4

#define TEMP_DESIRED_C 40
// #define TEMP_LOW_C 38
#define TEMP_LOW_C 11
#define TEMP_HIGH_HIGH_C 45
// #define TEMP_LOW_LOW_C 35
#define TEMP_LOW_LOW_C 10
#define LOWEST_POSSIBLE_TEMP -40 // for basic error checking on temp sensors
#define HIGHEST_POSSIBLE_TEMP 80

#define TEST_CYCLES 20

// #define REACTION_DURATION_MS 30 * 60 * 1000     // 30 minutes
#define REACTION_DURATION_MS 30 * 1000          // 30 seconds
#define TUBE_REACTION_DURATION_MS 5 * 1000

#define TEMP_LOW_DURATION_MS 5 * 60 * 1000      // 5 minutes
#define TEMP_EXTREME_DURATION_MS 10 * 1000      // 10 seconds

// ####################################
// DISPLAY AND INPUT CONSTANTS
// ####################################

#define DEBOUNCE_TIME_CYCLES 5
#define NUM_BUTTONS 4
#define REDRAW_INTERVAL_MS 500

#define MAX_FILES 10
#define MAX_NAME_LEN 21

// ####################################
// OPTICAL CONSTANTS
// ####################################

#define OPTICAL_REACTION_THRESHOLD 1000

// ####################################
// BUTTON DEFINITIONS
// ####################################

#define BACK_BUTTON_GPIO_PIN 14     // btn 1
#define DOWN_BUTTON_GPIO_PIN 15     // btn 0
#define UP_BUTTON_GPIO_PIN 12       // btn 3
#define SELECT_BUTTON_GPIO_PIN 13   // btn 2

static const int BUTTON_PINS[] = {
    UP_BUTTON_GPIO_PIN,
    DOWN_BUTTON_GPIO_PIN,
    SELECT_BUTTON_GPIO_PIN,
    BACK_BUTTON_GPIO_PIN,
};

// ####################################
// I2C DEFINITIONS
// ####################################

#define I2C_SDA_PIN 4
#define I2C_SCL_PIN 5
#define I2C_BAUDRATE 100 * 1000  // 100 kHz

#define TEMP_SENSOR_0_I2C_ADDRESS 0x18
#define TEMP_SENSOR_1_I2C_ADDRESS 0x19
#define TEMP_SENSOR_2_I2C_ADDRESS 0x1A
#define TEMP_SENSOR_3_I2C_ADDRESS 0x1B

// ####################################
// SPI DEFINITIONS
// ####################################

#define SPI0_SCK_PIN 18
#define SPI0_MOSI_PIN 19

#define DISPLAY_DC_A0_PIN 20    // A0 Data/Command pin - LOW=command, HIGH=data
#define DISPLAY_RST_PIN 21      // Reset pin - LOW=reset, HIGH=normal operation

#define SPI1_SCK_PIN 10
#define SPI1_MOSI_PIN 11
#define SPI1_MISO_PIN 8

#define SPI0_CSn_DISPLAY_PIN 17
#define SPI1_CSn_SD_CARD_PIN 0
#define SPI1_CS_SHIFT_SWITCHES_SR_PIN_0 26
#define SPI1_CS_SHIFT_SWITCHES_SR_PIN_1 27
#define SPI1_CSn_ADC0_PIN 9
#define SPI1_CSn_ADC1_PIN 7

#define HEATER_PIN 22

#define LED_PIN 1

#define SPI_INSTANCE_DISPLAY spi0   // for reference only, see PICO2W.h
#define SPI_INSTANCE_SD spi1        // for reference only, see hw_config.h
#define SPI_INSTANCE_SW spi1        // for reference only
#define SPI_INSTANCE_ADC spi1        // for reference only

#define PROBE_PIN 1

#define SPI0_BAUDRATE 4 * 1000 * 1000 / 4       // 4 MHz which is a limit from glcd
// #define SPI1_BAUDRATE 125 * 1000 * 1000 / 4     // 31.25 MHz, just the default from no-os-fatfs
#define SPI1_BAUDRATE 1000 * 1000

#endif

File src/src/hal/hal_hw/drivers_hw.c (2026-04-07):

#include "drivers.h"

#include "data_helpers.h"
#include "data_structs.h"
#include "constants.h"
#include <hardware/i2c.h>
#include <hardware/spi.h>
#include <stdint.h>
#include <stdio.h>
#include <stdlib.h>

#include <hardware/gpio.h>
#include "pico/time.h"

#ifdef CYW43_WL_GPIO_LED_PIN
#include "pico/cyw43_arch.h"
#endif

#ifdef USE_HW_PICO

// Turn the led on or off
void pico_set_led(bool led_on) {
    #if defined(PICO_DEFAULT_LED_PIN)
        // Just set the GPIO on or off
        gpio_put(PICO_DEFAULT_LED_PIN, led_on);
    #elif defined(CYW43_WL_GPIO_LED_PIN)
        // Ask the wifi "driver" to set the GPIO on or off
        cyw43_arch_gpio_put(CYW43_WL_GPIO_LED_PIN, led_on);
    #endif
}

uint32_t get_current_time(void) {
    return to_ms_since_boot(get_absolute_time());
}

void hw_leds_toggle(bool enable) {
    if (enable) {
        gpio_put(LED_PIN, 1);
        printf("Led pin set");
        gSystemInfo.led_state = true;
    } else {
        gpio_put(LED_PIN, 0);
        gSystemInfo.led_state = false;
    }
}

#endif

#ifdef USE_HW_BUTTONS
int hw_button_get_raw(int button_gpio) {
    return gpio_get(button_gpio);
}
#endif

#ifdef USE_HW_HEATER
void hw_heater_toggle(bool enable) {
    if (enable) {
        gpio_put(HEATER_PIN, 1);
        gHeaterState.heaterOn = true;
        // printf("Heater pin ON\n");
    } else {
        gpio_put(HEATER_PIN, 0);
        gHeaterState.heaterOn = false;
        // printf("Heater pin OFF\n");
    }
}
#endif

#ifdef USE_HW_TEMP_SENS

// adapted from 
// https://github.com/raspberrypi/pico-examples/blob/master/i2c/mcp9808_i2c/mcp9808_i2c.c
// into gemini
float mcp9808_convert_temp(uint8_t upper_byte, uint8_t lower_byte) {
    float temperature;

    // Mask the flags (Bits 15, 14, 13) out. 
    // 0x1F keeps only the Sign bit (bit 12) and the 4 integer bits.
    upper_byte = upper_byte & 0x1F; 

    // Check the SIGN bit (Bit 12 / 0x10)
    if ((upper_byte & 0x10) == 0x10) {
        // Negative Temperature logic
        upper_byte = upper_byte & 0x0F; // Clear sign bit for math
        temperature = 256.0 - (((float)upper_byte * 16.0) + ((float)lower_byte / 16.0));
    } else {
        // Positive Temperature logic
        // Mask upper_byte to 0x0F to ensure no flags interfere with math
        temperature = (((float)upper_byte) * 16.0) + ((float)lower_byte / 16.0);
    }

    return temperature;
}

float hw_read_temperature_sensor(int address) {

    // printf("Reading temperature sensor at address 0x%02X\n", address);
    const uint8_t reg = 0x05;
    uint8_t buf[2];
    
    int w = i2c_write_timeout_us(i2c0, address, &reg, 1, true, 50000);
    int r = i2c_read_timeout_us(i2c0, address, buf, 2, false, 50000);

    if ((r < 0) || (w < 0)) {
        gSystemInfo.temp_sensor_success_count--;
        if (gSystemInfo.temp_sensor_success_count < -5) {
            gSystemError.current_error = ERROR_TEMP_SENSOR_FAULT;
            gSystemInfo.temp_sensor_success_count = -6;
        }
        return -999;
    } else {
        gSystemInfo.temp_sensor_success_count++;
    }

    float temp = mcp9808_convert_temp(buf[0], buf[1]);

    // uint16_t raw = ((uint16_t)buf[0] << 8) | buf[1];
    // raw &= 0x1FFF;

    // float temp = raw * 0.0625f;

    // if (raw & 0x1000)
    //     temp -= 256.0f;

    if (temp < -40.0f || temp > 125.0f) {
        // Out of range, likely a faulty reading
        gSystemInfo.temp_sensor_success_count--;
        if (gSystemInfo.temp_sensor_success_count < -5) {
            // gSystemError.current_error = ERROR_TEMP_SENSOR_FAULT;
            gSystemInfo.temp_sensor_success_count = -6;
        }
        return -999;
    }

    return temp;
}

#endif

#ifdef USE_HW_OPTICAL

uint16_t read_mcp3208(uint8_t channel, int adc_csn_pin) {
    // Ensure we only use valid channels (0-7)
    if (channel > 7) return 0;

    uint8_t tx_buf[3];
    uint8_t rx_buf[3];

    // Byte 0: 0 0 0 0 0 Start(1) SGL(1) D2
    tx_buf[0] = 0x06 | ((channel >> 2) & 0x01); 
    
    // Byte 1: D1 D0 0 0 0 0 0 0
    tx_buf[1] = (channel & 0x03) << 6;          
    
    // Byte 2: Dummy byte to clock out the remaining data
    tx_buf[2] = 0x00;                           

    // Pull Chip Select low to initiate communication
    gpio_put(adc_csn_pin, 0);

    // Write the 3 bytes while simultaneously reading the response
    spi_write_read_blocking(SPI_INSTANCE_ADC, tx_buf, rx_buf, 3);

    // Push Chip Select high to end communication
    gpio_put(adc_csn_pin, 1);

    // Construct the 12-bit result from the response bytes
    // The first RX byte is ignored. 
    // The lower 4 bits of the second RX byte contain the upper 4 bits of the result.
    // The third RX byte contains the lower 8 bits of the result.
    uint16_t result = ((rx_buf[1] & 0x0F) << 8) | rx_buf[2];
    // printf("RAW BYTES: %02X %02X %02X from channel %d pin %d\n", rx_buf[0], rx_buf[1], rx_buf[2], channel, adc_csn_pin);

    return result;
}

uint16_t hw_adc_read_raw(int adc_csn_pin, int channel) {

    uint16_t adc_value = read_mcp3208(channel, adc_csn_pin);
    
    if (adc_value == 4095)
        adc_value = 0; // error reading

    return adc_value;

}

#endif

#ifdef USE_HW_TUBE_SENS

uint8_t hw_tube_sens_read_all(int pin) {
    uint8_t data;

    // Disable clock (CLKINH = 1)
    gpio_put(pin, 1);

    // Take MOSI away from SPI as I screwed up the pcb, plz forgive me
    gpio_set_function(SPI1_MOSI_PIN, GPIO_FUNC_SIO);
    gpio_set_dir(SPI1_MOSI_PIN, GPIO_OUT);

    // Parallel load
    gpio_put(SPI1_MOSI_PIN, 0);
    sleep_us(1);
    gpio_put(SPI1_MOSI_PIN, 1);
    sleep_us(1);

    // Give MOSI back to SPI
    gpio_set_function(SPI1_MOSI_PIN, GPIO_FUNC_SPI);

    // Enable clock
    gpio_put(pin, 0);

    // Clock 8 bits
    spi_read_blocking(SPI_INSTANCE_SW, 0xFF, &data, 1);

    // Disable clock again
    gpio_put(pin, 1);

    return ~data;   // because QH* is inverted output
}

#endif

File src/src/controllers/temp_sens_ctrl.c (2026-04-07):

#include "temp_sens_ctrl.h"

#include "data_helpers.h"
#include "drivers.h"

#include "constants.h"
#include "data_structs.h"
#include <stdio.h>

// for demo only so i dont have to reflash
float read_sensor_sw(int sensor_id) {

    if (gSimParams.force_temp_sensor_fault) return -999.0f;

    // if heater is on, temp goes up
    if (gHeaterState.heaterOn == true) {
        gTempStatus.chamber_temp += gSimParams.heat_rate;
    } else {
        if (gTempStatus.chamber_temp > gSimParams.ambient_temp) {
            gTempStatus.chamber_temp -= gSimParams.cool_rate;
        }
    }

    return gTempStatus.chamber_temp;
}

// Read temp status into gTempStatus
void temp_sens_ctrl_step(void) {

    if (DEBUG_MODE) {
        gTempStatus.temp_readings[0] = read_sensor_sw(TEMP_SENSOR_0_I2C_ADDRESS);
        gTempStatus.temp_readings[1] = read_sensor_sw(TEMP_SENSOR_1_I2C_ADDRESS);
    } else {
        gTempStatus.temp_readings[0] = hw_read_temperature_sensor(TEMP_SENSOR_0_I2C_ADDRESS);
        gTempStatus.temp_readings[1] = hw_read_temperature_sensor(TEMP_SENSOR_1_I2C_ADDRESS);
        gTempStatus.temp_readings[2] = hw_read_temperature_sensor(TEMP_SENSOR_2_I2C_ADDRESS);
        gTempStatus.temp_readings[3] = hw_read_temperature_sensor(TEMP_SENSOR_3_I2C_ADDRESS);
    }

    gTempStatus.chamber_temp = gTempStatus.temp_readings[0]; // Assuming chamber temperature is from the second sensor
    
    gTempStatus.temp_low = (gTempStatus.chamber_temp < TEMP_LOW_LOW_C);
    gTempStatus.temp_extreme = (gTempStatus.chamber_temp < TEMP_LOW_LOW_C || 
                                        gTempStatus.chamber_temp > TEMP_HIGH_HIGH_C);
    gTempStatus.target_reached = (gTempStatus.chamber_temp >= gTempStatus.target_temp);
}

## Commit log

2025-12-06 Added hardware schematics
    [cme495_pcb.kicad_pcb, cme495_pcb.kicad_sch, power_splitter - Copy.kicad_sch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]
2025-12-11 blink.c, builds for my pico w. can be changed to pico 2 easily
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2025-12-13 takes 4 gpio button inputs and sends the detections to serial output on usb. debouncing as well from a... friend...
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2025-12-14 a slightly hideous redraw fix. will need to improve organization
    [constants.h, main.c, temp_sens_ctrl.c]
2025-12-15 display and button input running on second core :) considering some sempahore on the now global system state and some cleanup in display especially
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2025-12-23 more displays and cleanup, tube struct changes which may not stay permanent
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2026-01-12 fixes, debug to insert tubes
2026-01-12 added xh connector plans
    [cme495_pcb.kicad_sch]
2026-01-13 pins changed
    [cme495_pcb.kicad_sch]
2026-01-15 Added KiCad parts to library for circuit layout.
    [B4B-XH-A.step, B8B-XH-A.step, C1206C104K5RACTU.step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]
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2026-01-20 main pcb design and draft display pcb
    [B6B-XH-A.step, display-pcb.kicad_pcb, display-pcb.kicad_sch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]
2026-01-20 draft tube detection pcb
    [tube_detection_pcb.kicad_pcb, tube_detection_pcb.kicad_sch]
2026-01-21 changes to display and tube pcb
    [display-pcb.kicad_pcb, display-pcb.kicad_sch, tube_detection_pcb.kicad_pcb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]
2026-01-21 wiring plan updates
    [pcb-wiring-plan.kicad_sch]
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2026-01-27 pcb silkscreens mostly
    [display-pcb.kicad_pcb, display-pcb.kicad_sch, tube_detection_pcb.kicad_pcb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]
2026-01-27 testing and a stupid bug in heater ctrl
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2026-01-28 Added MCP9808 example code (to be tested)
    [mcp9808_i2c.fzz]
2026-01-28 Main PCB project committed.
    [main_pcb.kicad_pcb, main_pcb.kicad_sch]
2026-01-28 updated power circuit
    [PJ-082BH.step, power_splitter.kicad_pcb, power_splitter.kicad_sch]
2026-01-29 pcb stuff i forget
    [display-pcb.kicad_pcb, display-pcb.kicad_sch, tube_detection_pcb.kicad_pcb]
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2026-01-30 sd read and write :) still some organization problems, tests dont compile
    [screens_sw.c]
2026-01-30 pcb repin
    [tube_detection_pcb.kicad_pcb, tube_detection_pcb.kicad_sch]
2026-01-31 Added switch board connector and display board connector circuitry to main pcb.
    [main_pcb.kicad_sch]
2026-01-31 Finished circuit layout for the main PCB exlcuding the fan headers.
    [main_pcb.kicad_sch]
2026-01-31 Added pi 1x20 pin socket for now (subject to change).
    [main_pcb.kicad_sch]
2026-01-31 Added fan and sd card header among other things to the main pcb.
    [main_pcb.kicad_sch]
2026-01-31 Started preliminary layout of the main PCB.
    [main_pcb.kicad_pcb]
2026-01-31 power stuff
    [power_splitter.kicad_pcb, power_splitter.kicad_sch]
2026-01-31 PCB updates
    [display-pcb.kicad_pcb, display-pcb.kicad_sch, tube_detection_pcb.kicad_pcb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]
2026-01-31 forgor pcb
    [display-pcb.kicad_pcb]
2026-01-31 Started layout of the main PCB. God help me for I have sinned :(
    [main_pcb.kicad_pcb, main_pcb.kicad_sch]
2026-02-01 pcb i forgot?
    [display-pcb.kicad_pcb]
2026-02-01 And falling into a place where two layers met, they ran the PCB aground; and the forepart stuck fast, and remained unmoveable, but the hinder part was broken with the violence of the photodiodes.
    [main_pcb.kicad_pcb, main_pcb.kicad_sch]
2026-02-01 The PCB is the resurrection and the life; he that believeth in it, though it were dead, yet shall he live.
    [main_pcb.kicad_pcb, main_pcb.kicad_sch]
2026-02-02 Rejoice always, pray continually, give thanks in all circumstances, for this is the PCB’s will for you.
    [main_pcb.kicad_pcb, main_pcb.kicad_sch]
2026-02-02 When a man's ways please the PCB, he makes even his enemies to be at peace with him
    [main_pcb.kicad_pcb]
2026-02-02 Do not fear, for the PCB hath redeemed you. It has called you by name, and you belong to it
    [main_pcb.kicad_pcb]
2026-02-02 There is none holy like the PCB: for there is none besides it; there is no rock like our PCB
    [main_pcb.kicad_pcb]
2026-02-02 Added ground plane to top layer of PCB.
    [main_pcb.kicad_pcb]
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2026-02-04 Added heater actuation header.
    [B2B-XH-A.step, main_pcb.kicad_pcb]
2026-02-04 Liv's stuff
    [power_splitter.kicad_sch]
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2026-02-04 pcb finishing touches
    [display-pcb.kicad_pcb, display-pcb.kicad_sch, tube_detection_pcb.kicad_pcb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]
2026-02-05 Updated and tweaked main PCB
    [main_pcb.kicad_pcb, main_pcb.kicad_sch]
2026-02-05 Fixed some stuff and made the main PCB smaller.
    [main_pcb.kicad_pcb, main_pcb.kicad_sch]
2026-02-06 Fully seperated analog ground from digital ground on the main PCB.
    [DMG2305UX-7.step, main_pcb.kicad_pcb, main_pcb.kicad_sch]
2026-02-06 debug menu
    [display-pcb-job.gbrjob]
2026-02-06 Switched around regsel and reset pins for display header on main PCB.
    [main_pcb.kicad_pcb, main_pcb.kicad_sch]
2026-02-08 Added gerber_files directory
    [main_pcb-job.gbrjob]
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2026-02-08 power pcb gerbers
    [power_splitter-job.gbrjob]
2026-02-08 old gerber
    [display-pcb-job.gbrjob]
2026-02-27 generated 3D files for each of the boards
    [display-pcb.stl, tube_detection_pcb.stl]
2026-03-02 Updated main PCB
    [main_pcb.kicad_pcb, main_pcb.kicad_sch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]
2026-03-02 A lot of changes, display logic and some error handling
    [main_pcb.kicad_pcb, main_pcb.kicad_sch]
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2026-03-04 Error handling and sd card stuff
    [board_setup.c, button_ctrl.c, drivers_hw.c]
2026-03-05 new power PCB
    [power_splitter - Copy.kicad_sch, power_splitter.kicad_pcb, power_splitter.kicad_sch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]
2026-03-05 Preliminary chassis design for the presentation. Fuck my life i'm tired and still need to do ethics
    [chassis.stl]
2026-03-06 trying again
    [power_splitter.kicad_sch]
2026-03-06 I am become death, destroyer of PCBs.
    [main_pcb.kicad_pcb, main_pcb.kicad_sch]
2026-03-06 SD fixes and debug menu
    [board_setup.c, drivers_hw.c, main.c]
2026-05-05 move files
    [mcp9808_i2c.fzz]
2026-05-05 file removal
    [chassis.stl, cme495_pcb.kicad_pcb, cme495_pcb.kicad_sch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]
